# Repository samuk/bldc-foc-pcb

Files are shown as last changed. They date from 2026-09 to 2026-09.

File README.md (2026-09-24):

# FOC BLDC Motor Controller

> High-performance Field-Oriented Control driver built around the **STM32G474** MCU and **DRV8308** gate driver.

**[🌐 Live Project Page](https://bejaouihamza.github.io/bldc-foc-pcb/)**

[Kicanvas](https://kicanvas.org/?repo=https%3A%2F%2Fgithub.com%2Fsamuk%2Fbldc-foc-pcb%2Ftree%2Fmain%2Fkicad)

---

## Overview

This open-source hardware project is a compact, single-board FOC (Field-Oriented Control) motor driver designed for precision robotics, drones, CNC machines, and automation systems. It delivers smooth sinusoidal torque control with minimal audible noise thanks to Space Vector PWM (SVPWM) modulation.

| Spec | Value |
|---|---|
| Input Voltage | 8.5V – 32V DC |
| Max Continuous Current | 50A |
| Peak Current | 100A (transient) |
| MCU | STM32G474CBTx (170 MHz, Cortex-M4) |
| Gate Driver | DRV8308 (SPI-configurable) |
| MOSFETs | 6× BSC098N10NS5 (100V, 9.8mΩ) |
| PWM Frequency | 20 kHz (center-aligned) |
| Commutation | Trapezoidal or 180° sinusoidal FOC |
| Sensors | 3× Hall differential inputs |
| Interface | USB-C + ARM SWD debug |

---

## Hardware

### PCB Layout (Top Layer)

PCB Top Layer Layout

The top layer shows the complete copper layout with phase outputs **U, V, W** at the top, power input (**XT60**) on the left, and the control section (STM32G474 + DRV8308) in the center. Note the star-grounding strategy and wide power traces for high-current paths.

### 3D Render

PCB 3D Render

Compact form factor (~85mm × 55mm) with 4× M3 mounting holes. The large electrolytic capacitors handle bulk energy storage while the XT60 connector delivers main battery power.

### Schematic

Full Schematic

The design is organized into clear functional blocks:
- **Power Input & Protection** — XT60 connector, fuse, reverse-polarity diode, LTC4359 ideal diode
- **5V Buck** — LM5164DDA switching regulator
- **3.3V LDO** — TLV75533 for clean logic supply
- **MCU** — STM32G474 with 24MHz crystal, USB-C, SWD, BOOT/RESET switches
- **FOC Unit** — DRV8308 gate driver with SPI configuration
- **Power Stage** — 6× BSC098N10NS5 MOSFETs in 3-phase bridge configuration
- **Hall Sensors** — 3× DRV5013 with 4.7kΩ pull-ups and VREG supply

---

## Architecture

### FOC Control Loop

```
                Speed Ref (ω*) → Speed PI → Iq*
                                ↓
                    ┌─────────────────┐
Id*=0 → Current PI  │  Inverse Park   │ → Vα,Vβ → SVPWM → DRV8308 → 3-Phase Bridge → Motor
  Iq → Current PI   │  (d-q → α-β)    │         ↑
                    └─────────────────┘         │
                            ↑                   │
  Hall → Estimator → θ,ω    │                   │
           ↑                │                   │
    Current Sense → Clarke → Park → Id,Iq (feedback)
```

The STM32G474 runs the full FOC algorithm:
1. **Speed PI** — compares reference vs. actual speed, outputs torque command
2. **Current PI (×2)** — regulates Id=0 and Iq=Iq* in the rotating d-q frame
3. **Inverse Park** — converts Vd,Vq → Vα,Vβ (rotating → stationary)
4. **SVPWM** — Space Vector modulation for 15% better DC bus utilization vs. sine PWM
5. **Feedback** — Hall sensors provide rotor position; 5mΩ shunt (R1) senses phase current

### Critical Pin Assignment

| Pin | Function | Connected To |
|-----|---|---|
| **PA8** | TIM1_CH1 / CLKIN | DRV8308 CLKIN *(most important!)* |
| PA4-PA7 | SPI1 | DRV8308 SCS/SCLK/SDATAO/SDATAI |
| PB0 | DIRECTION | DRV8308 DIR |
| PB1 | SHDN | DRV8308 SHDN |
| PB7 | ENABLE | DRV8308 ENABLE |
| PB4 | FAULTn | DRV8308 FAULTn (input) |

> ⚠️ **TIM1_CH1 on PA8 is critical** — it synchronizes DRV8308 internal commutation timing. Moving it to a general-purpose timer breaks center-aligned PWM alignment.

---

## Firmware

### STM32 HAL Example

```c
/* Initialize DRV8308 for 180° sinusoidal FOC */
void DRV8308_Init(void) {
    // SYSOPT1: Enable sine mode
    DRV8308_WriteReg(DRV8308_SYSOPT1, 0x8000);  // SINMODE=1

    // SYSOPT2: 50mA gate drive for BSC098N10NS5
    DRV8308_WriteReg(DRV8308_SYSOPT2, 0x0300);  // IDRIVE=011

    // SYSOPT3: 1µs dead time
    DRV8308_WriteReg(DRV8308_SYSOPT3, 0x0040);

    // SYSOPT9: 50A overcurrent (0.25V / 5mΩ)
    DRV8308_WriteReg(DRV8308_SYSOPT9, 0x0000);
}

/* TIM1 center-aligned PWM for CLKIN */
void TIM1_PWM_Init(void) {
    htim1.Instance = TIM1;
    htim1.Init.Prescaler = 0;
    htim1.Init.CounterMode = TIM_COUNTERMODE_CENTERALIGNED1;
    htim1.Init.Period = 4250;  // 170MHz / (2×4250) = 20kHz
    // ...
    HAL_TIM_PWM_Start(&htim1, TIM_CHANNEL_1);
}
```

### Arduino / SimpleFOC

Also compatible with the [SimpleFOC](https://simplefoc.com/) library for rapid prototyping:

```cpp
BLDCMotor motor = BLDCMotor(11);  // 11 pole pairs
BLDCDriver3PWM driver = BLDCDriver3PWM(9, 10, 11, 8);
HallSensor sensor = HallSensor(2, 3, 4, 11);

motor.foc_modulation = FOCModulationType::SpaceVectorPWM;
motor.controller = MotionControlType::velocity;
motor.init();
motor.initFOC();
```

See the **[live project page](https://bejaouihamza.github.io/bldc-foc-pcb/)** for the complete code examples, wiring guide, and interactive SVPWM block diagram.

---

## Wiring

| Connection | Pin/Port | Notes |
|---|---|---|
| Battery | XT60 | 8.5-32V DC |
| Motor U/V/W | Top screw terminals | Thick wire, high current |
| Hall VCC | VREG pin | 5V from DRV8308 |
| Hall GND | GND pin | Common ground |
| Hall signals | UHP/UHN, VHP/VHN, WHP/WHN | Differential pairs |
| Programming | SWD header | ST-Link V2/V3 |
| Serial/USB | USB-C | DFU bootloader + CDC |

---

## Bill of Materials (Key Components)

| Ref | Part | Description |
|-----|---|---|
| U1 | STM32G474CBTx | 170 MHz Cortex-M4 MCU |
| U2 | DRV8308 | 3-phase gate driver with SPI |
| Q1-Q6 | BSC098N10NS5 | 100V, 9.8mΩ N-channel MOSFET |
| U6 | LM5164DDA | 5V buck converter |
| U7 | TLV75533PDBV | 3.3V LDO |
| U8 | LTC4359 | Ideal diode controller |
| U3-U5 | DRV5013 | Hall sensors |
| Y1 | 24 MHz | Crystal oscillator |
| J1 | XT60PW-M | Battery connector |
| J5 | USB-C | USB 2.0 receptacle |

---

## Protection Features

- ✅ Reverse polarity (LTC4359 + diode)
- ✅ Overcurrent (cycle-by-cycle, 50A limit)
- ✅ Undervoltage lockout (UVLO)
- ✅ Overtemperature shutdown
- ✅ Rotor lock detection
- ✅ Fuse on battery input

---

## Getting Started

1. **Power up** — Connect 12-24V battery to XT60. Verify 5V and 3.3V LEDs.
2. **Connect motor** — Wire BLDC phases and Hall sensors.
3. **Flash firmware** — Use ST-Link on SWD header or DFU over USB-C.
4. **Configure DRV8308** — Run SPI init sequence (see code above).
5. **Spin** — Enable driver, set direction, send CLKIN frequency. Start at 100 Hz, ramp up slowly.

---

## Project Structure

```
bldc-foc-pcb/
├── README.md                          # Project overview and documentation
├── index.html                         # GitHub Pages project page
├── pcb-layout-top.png                 # Top-layer PCB layout
├── pcb-render.png                     # 3D render of the assembled PCB
├── schematic-full.png                 # Complete circuit schematic
├── bldc&foc motor controller.zip      # Complete KiCad project source
├── bldcfoc_motor_controller.zip       # Manufacturing files (Gerbers, drill, etc.)
├── bom.csv                            # Bill of Materials for assembly
├── designators.csv                    # Reference designator list
├── netlist.ipc                        # IPC-D-356 netlist for verification
└── positions.csv                      # Pick-and-place coordinates for SMT assembly
```

---

## License

Open source hardware. Feel free to use, modify, and distribute. Attribution appreciated.

---

**Designed by [bejaoui hamza](https://github.com/bejaouihamza)** · KiCad EDA 10.0.1

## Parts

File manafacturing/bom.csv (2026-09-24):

Designator | Footprint | Quantity | Value | LCSC Part #
C1, C19, C20 | CP_Elec_8x10.5 | 3 | 470u
C10, C25, C27 | 0603 | 3 | 0.01U
C11 | 0603 | 1 | 2.2n
C12 | 0805 | 1 | 2.2u
C13 | CP_EIA-3528-21_Kemet-B | 1 | 47u
C14, C15, C24, C26, C3, C5 | 0805 | 6 | 1u
C16, C17, C18 | CP_Elec_6.3x7.7 | 3 | 220u
C2, C21, C22, C23, C4, C6, C7, C8, C9 | 0603 | 9 | 0.1u
C28, C29 | 0603 | 2 | 15P
D1 | D_SMC | 1 | 1.5SMCxxCA
D12, D13 | 0805 | 2 | LED_Small | C2297
D2, D3 | D_SMC | 2 | MBRS340
F1 | Fuse_Blade_Mini_directSolder | 1 | Fuse
FB1 | 1210 | 1 | FerriteBead
J1 | AMASS_XT60PW-M | 1 | XT60PW-M
J5 | USB_C_Receptacle_HRO_TYPE-C-31-M-12 | 1 | USB_C_Receptacle_USB2.0_14P | C165948
L1 | L_APV_ANR4012 | 1 | 68u
Q1, Q2, Q3, Q4, Q5, Q6 | TDSON-8-1 | 6 | BSC098N10NS5
Q7 | TDSON-8-1 | 1 | BSC026N08NS5
R1 | 2512 | 1 | 5m
R10, R11, R2, R4, R5, R6, R7, R8, R9 | 0603 | 9 | 4.7K
R12 | 0603 | 1 | 475k
R13 | 0603 | 1 | 150k
R14, R32 | 0603 | 2 | 100k
R15, R30 | 0603 | 2 | 5.1K | C27834
R16, R18, R23, R28, R29 | 0603 | 5 | 22
R17, R19, R20, R21, R22, R24, R25, R26, R27, R31, R37 | 0603 | 11 | 10k
R33 | 0603 | 1 | 1k
R34 | 0603 | 1 | 100
R59, R60 | 0402 | 2 | 1.5k
SW1, SW2 | SW_TH_Tactile_Omron_B3F-100x | 2 | SW_Push_Dual_x2
TP1, TP2, TP3, TP4 | TestPoint_Pad_D1.5mm | 4 | TestPoint
U1 | LQFP-48_7x7mm_P0.5mm | 1 | STM32G474CBTx
U11 | SOT-23-6 | 1 | USBLC6-2SC6
U2 | Texas_RHA0040E_VQFN-40-1EP_6x6mm_P0.5mm_EP3.52x2.62mm | 1 | DRV8308
U6 | HSOP-8-1EP_3.9x4.9mm_P1.27mm_EP2.41x3.1mm_ThermalVias | 1 | LM5164DDA
U7 | SOT-23-5 | 1 | TLV75533PDBV
U8 | DFN-6-1EP_3x2mm_P0.5mm_EP1.65x1.35mm | 1 | LTC4359-DCB
Y1 | Crystal_SMD_3225-4Pin_3.2x2.5mm | 1 | Crystal_GND23

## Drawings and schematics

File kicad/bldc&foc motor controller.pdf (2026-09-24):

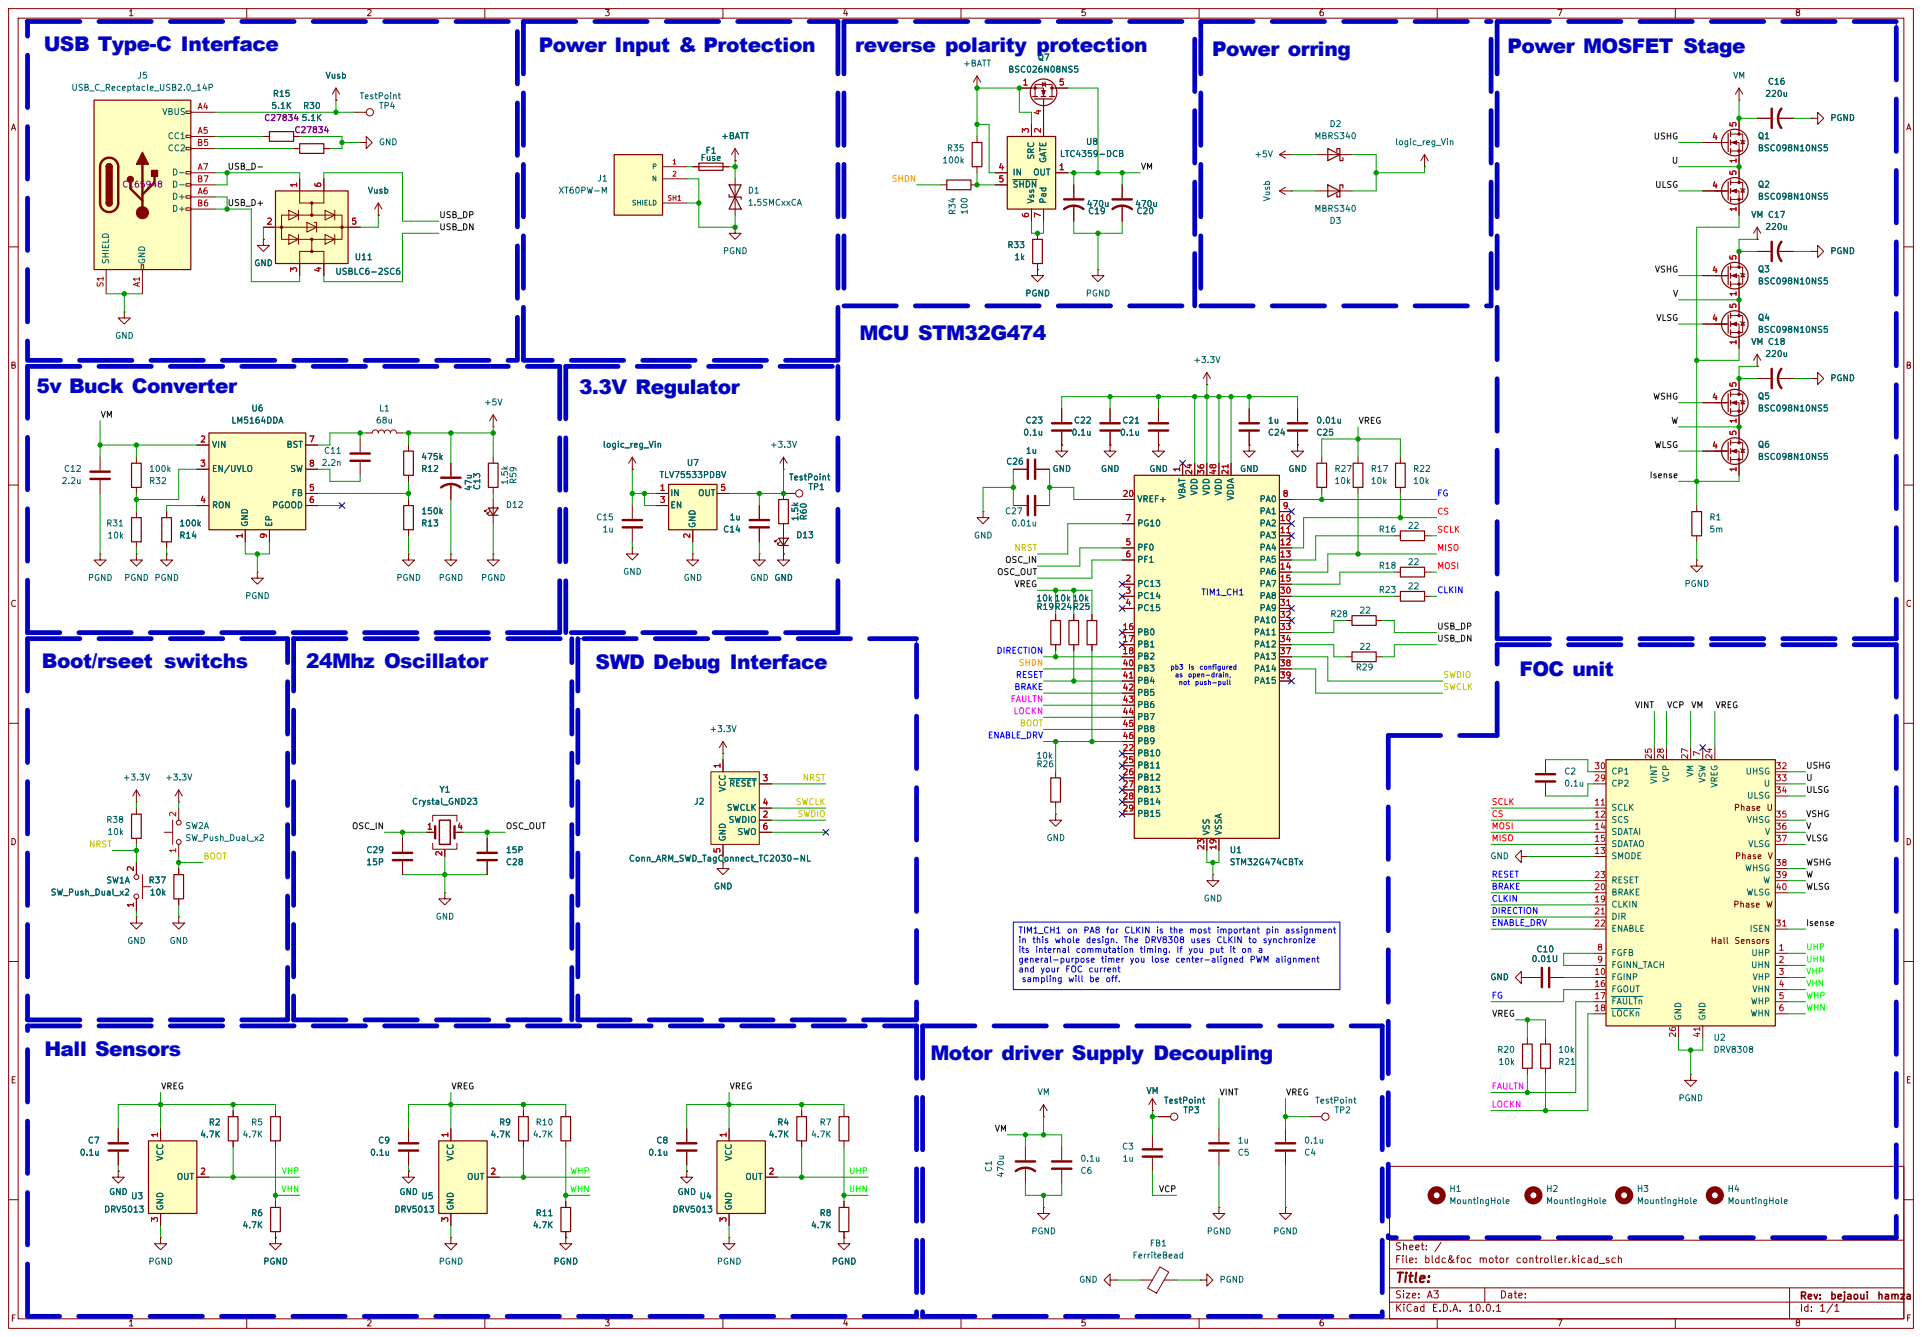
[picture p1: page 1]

pb3 is configured as open-drain, not push-pull

TIM1_CH1 on PA8 for CLKIN is the most important pin assignment
in this whole design. The DRV8308 uses CLKIN to synchronize
its internal commutation timing. If you put it on a
general-purpose timer you lose center-aligned PWM alignment and your FOC current sampling will be off.

Motor driver Supply Decoupling

File: bldc&foc motor controller.kicad_sch
Title:

F Date:

KiCad E.D.A. 10.0.1 | Id: 1/1

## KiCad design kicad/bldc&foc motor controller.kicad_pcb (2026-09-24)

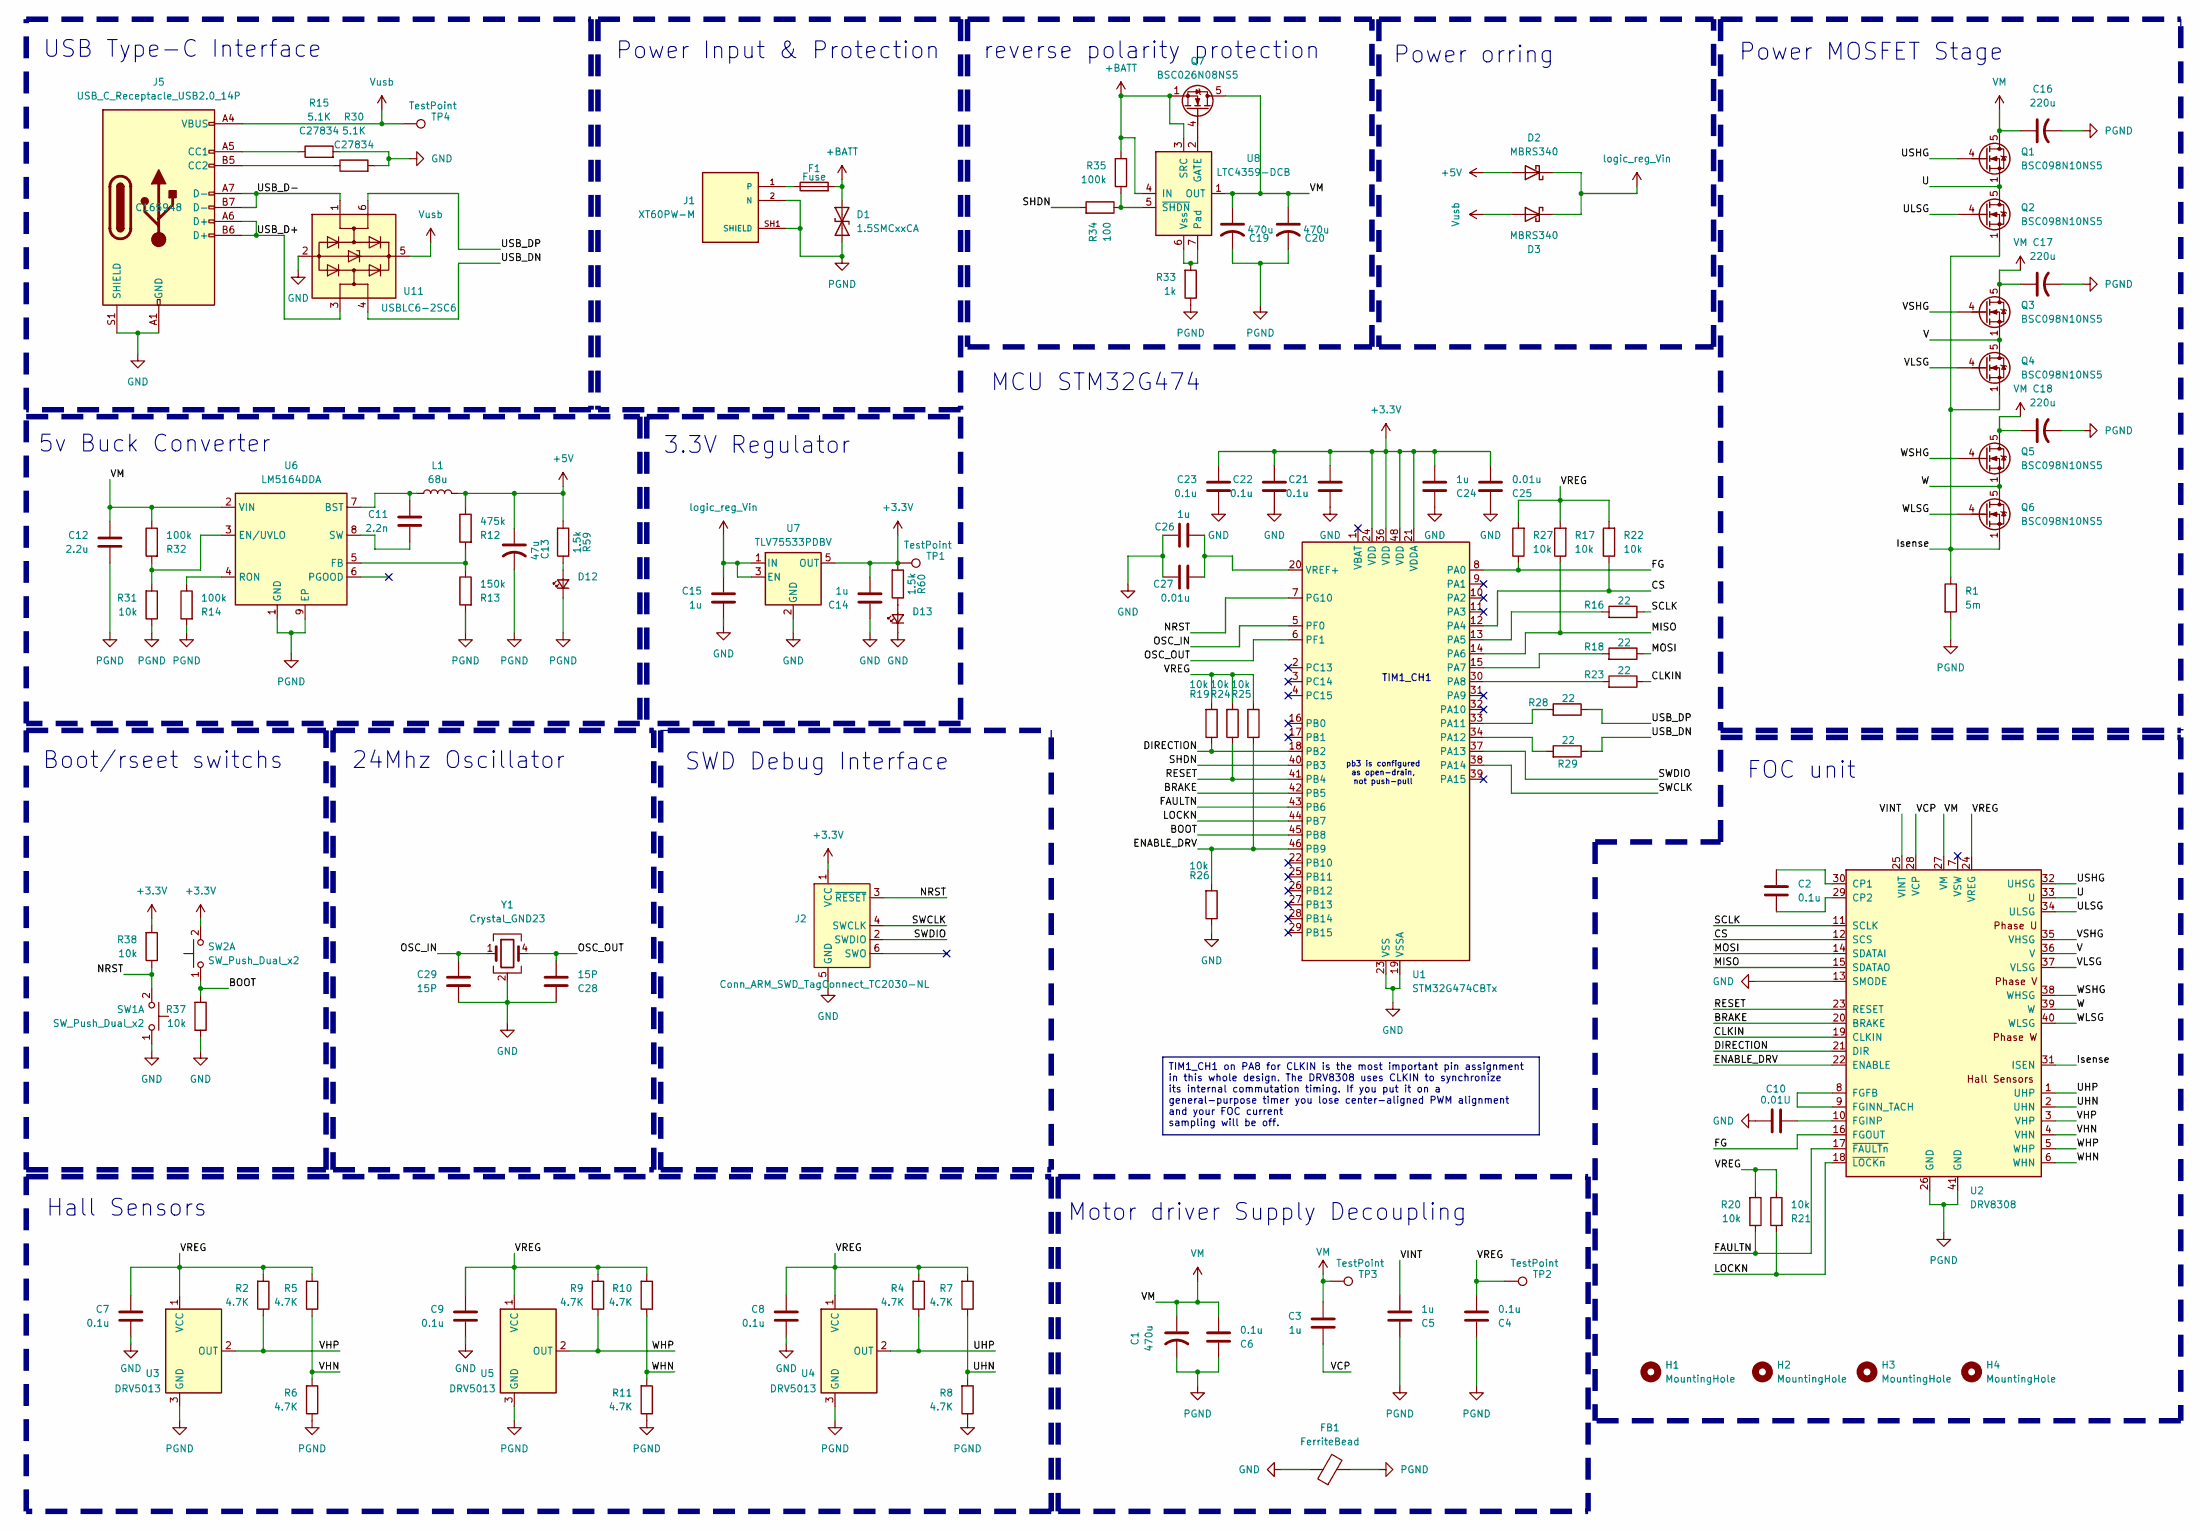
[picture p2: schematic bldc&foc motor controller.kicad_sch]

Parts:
C1, C19, C20: 470u; CP_Elec_8x10.5
C2, C4, C6, C7, C8, C9, C21, C22, C23: 0.1u; C_0603_1608Metric
C3, C5, C14, C15, C24, C26: 1u; C_0805_2012Metric
C10: 0.01U; C_0603_1608Metric
C11: 2.2n; C_0603_1608Metric
C12: 2.2u; C_0805_2012Metric
C13: 47u; CP_EIA-3528-21_Kemet-B
C16, C17, C18: 220u; CP_Elec_6.3x7.7
C25, C27: 0.01u; C_0603_1608Metric
C28, C29: 15P; C_0603_1608Metric
D1: 1.5SMCxxCA; D_SMC
D2, D3: MBRS340; D_SMC
D12, D13: LED_Small; LED_0805_2012Metric; LCSC Part # C2297
F1: Fuse; Fuse_Blade_Mini_directSolder
FB1: FerriteBead; L_1210_3225Metric
H1, H2, H3, H4: MountingHole; MountingHole_3.5mm_Pad_TopBottom
J1: XT60PW-M; AMASS_XT60PW-M; PARTREV 1.2
J2: Conn_ARM_SWD_TagConnect_TC2030-NL; Tag-Connect_TC2030-IDC-NL_2x03_P1.27mm_Vertical
J5: USB_C_Receptacle_USB2.0_14P; USB_C_Receptacle_HRO_TYPE-C-31-M-12; LCSC Part # C165948
L1: 68u; L_APV_ANR4012
Q1, Q2, Q3, Q4, Q5, Q6: BSC098N10NS5; TDSON-8-1
Q7: BSC026N08NS5; TDSON-8-1
R1: 5m; R_2512_6332Metric
R2, R4, R5, R6, R7, R8, R9, R10, R11: 4.7K; R_0603_1608Metric
R12: 475k; R_0603_1608Metric
R13: 150k; R_0603_1608Metric
R14, R32: 100k; R_0603_1608Metric
R15, R30: 5.1K; R_0603_1608Metric; LCSC Part # C27834
R16, R18, R23, R28, R29: 22; R_0603_1608Metric
R17, R19, R20, R21, R22, R24, R25, R26, R27, R31, R37: 10k; R_0603_1608Metric
R33: 1k; R_0603_1608Metric
R34: 100; R_0603_1608Metric
R35: 100k
R38: 10k
R59, R60: 1.5k; R_0402_1005Metric
SW1, SW2: SW_Push_Dual_x2; SW_TH_Tactile_Omron_B3F-100x
TP1, TP2, TP3, TP4: TestPoint; TestPoint_Pad_D1.5mm
U1: STM32G474CBTx; LQFP-48_7x7mm_P0.5mm
U2: DRV8308; Texas_RHA0040E_VQFN-40-1EP_6x6mm_P0.5mm_EP3.52x2.62mm
U3, U4, U5: DRV5013; SOT-23
U6: LM5164DDA; HSOP-8-1EP_3.9x4.9mm_P1.27mm_EP2.41x3.1mm_ThermalVias
U7: TLV75533PDBV; SOT-23-5
U8: LTC4359-DCB; DFN-6-1EP_3x2mm_P0.5mm_EP1.65x1.35mm
U11: USBLC6-2SC6; SOT-23-6; Manufacturer_Part_Number USBLC6-2SC6; Mouser Part Number 511-USBLC6-2SC6
Y1: Crystal_GND23; Crystal_SMD_3225-4Pin_3.2x2.5mm

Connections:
+3.3V: C14.2, C21.1, C22.1, C23.1, C24.2, C25.2, J2.1 (VCC), R38.2, R60.2, SW2.2 (D), TP1.1 (1_1), U1.21 (VDDA), U1.24 (VDD), U1.36 (VDD), U1.48 (VDD), U7.5 (OUT)
+5V: C13.1, D2.2 (A), L1.2, R12.1, R59.2
+BATT: D1.1 (A1), F1.2, Q7.1 (S), Q7.2 (S), Q7.3 (S), R35.2, U8.3 (SRC), U8.4 (IN)
/BOOT: R37.2, SW2.1 (C), U1.45 (PB8)
/BRAKE: U1.42 (PB5), U2.20 (BRAKE)
/CLKIN: R23.1, U2.19 (CLKIN)
/CS: R22.1, U1.12 (PA4), U2.12 (SCS)
/DIRECTION: R19.1, U1.18 (PB2), U2.21 (DIR)
/ENABLE_DRV: R25.1, R26.2, U1.46 (PB9), U2.22 (ENABLE)
/FAULTN: R20.1, U1.43 (PB6), U2.17 (~FAULTn)
/FG: R27.1, U1.8 (PA0), U2.16 (FGOUT)
/Isense: Q2.1 (S), Q2.2 (S), Q2.3 (S), Q4.1 (S), Q4.2 (S), Q4.3 (S), Q6.1 (S), Q6.2 (S), Q6.3 (S), R1.1, U2.31 (ISEN)
/LOCKN: R21.2, U1.44 (PB7), U2.18 (~LOCKn)
/MISO: R17.1, U1.14 (PA6), U2.15 (SDATAO)
/MOSI: R18.1, U2.14 (SDATAI)
/NRST: J2.3 (~RESET), R38.1, SW1.2 (D), U1.7 (PG10)
/OSC_IN: C29.1, U1.5 (PF0), Y1.1
/OSC_OUT: C28.2, U1.6 (PF1), Y1.4
/RESET: R24.1, U1.41 (PB4), U2.23 (RESET)
/SCLK: R16.1, U2.11 (SCLK)
/SHDN: R34.2, U1.40 (PB3)
/SWCLK: J2.4 (SWCLK), U1.38 (PA14)
/SWDIO: J2.2 (SWDIO), U1.37 (PA13)
/U: Q1.1 (S), Q1.2 (S), Q1.3 (S), Q2.5 (D), U2.33 (U)
/UHN: R7.1, R8.2, U2.2 (UHN)
/UHP: R4.1, U2.1 (UHP), U4.2 (OUT)
/ULSG: Q2.4 (G), U2.34 (ULSG)
/USB_D+: J5.A6 (D+), J5.B6 (D+), U11.3 (I/O2)
/USB_D-: J5.A7 (D-), J5.B7 (D-), U11.1 (I/O1)
/USB_DN: R29.1, U11.4 (I/O2)
/USB_DP: R28.1, U11.6 (I/O1)
/USHG: Q1.4 (G), U2.32 (UHSG)
/V: Q3.1 (S), Q3.2 (S), Q3.3 (S), Q4.5 (D), U2.36 (V)
/VCP: C3.2, U2.28 (VCP)
/VHN: R5.1, R6.2, U2.4 (VHN)
/VHP: R2.1, U2.3 (VHP), U3.2 (OUT)
/VINT: C5.2, U2.25 (VINT)
/VLSG: Q4.4 (G), U2.37 (VLSG)
/VREG: C4.2, C7.1, C8.1, C9.1, R2.2, R4.2, R5.2, R7.2, R9.2, R10.2, R17.2, R19.2, R20.2, R21.1, R22.2, R24.2, R25.2, R27.2, TP2.1 (1_1), U2.24 (VREG), U3.1 (VCC), U4.1 (VCC), U5.1 (VCC)
/VSHG: Q3.4 (G), U2.35 (VHSG)
/W: Q5.1 (S), Q5.2 (S), Q5.3 (S), Q6.5 (D), U2.39 (W)
/WHN: R10.1, R11.2, U2.6 (WHN)
/WHP: R9.1, U2.5 (WHP), U5.2 (OUT)
/WLSG: Q6.4 (G), U2.40 (WLSG)
/WSHG: Q5.4 (G), U2.38 (WHSG)
GND: C7.2, C8.2, C9.2, C10.2, C14.1, C15.2, C21.2, C22.2, C23.2, C24.1, C25.1, C26.1, C27.1, C28.1, C29.2, D13.1 (K), FB1.1, J2.5 (GND), J5.A1 (GND), J5.A12 (GND), J5.B1 (GND), J5.B12 (GND), J5.S1 (SHIELD), R15.2, R26.1, R30.2, R37.1, SW1.1 (C), U1.19 (VSSA), U1.23 (VSS), U1.35 (VSS), U1.47 (VSS), U2.13 (SMODE), U7.2 (GND), U11.2 (GND), Y1.2 (G), Y1.3 (G)
unnamed: D12.2 (A), R59.1
unnamed: D13.2 (A), R60.1
unnamed: F1.1, J1.1
unnamed: J5.A5 (CC1), R15.1
unnamed: J5.B5 (CC2), R30.1
unnamed: Q7.4 (G), U8.2 (GATE)
unnamed: R16.2, U1.13 (PA5)
unnamed: R18.2, U1.15 (PA7)
unnamed: R23.2, U1.30 (PA8)
unnamed: R28.2, U1.33 (PA11)
unnamed: R29.2, U1.34 (PA12)
unnamed: C26.2, C27.2, U1.20 (VREF+)
unnamed: C2.1, U2.30 (CP1)
unnamed: C2.2, U2.29 (CP2)
unnamed: U2.8 (FGFB), U2.9 (FGINN_TACH)
unnamed: C10.1, U2.10 (FGINP)
unnamed: C11.1, L1.1, U6.7 (BST)
unnamed: R31.2, R32.2, U6.3 (EN/UVLO)
unnamed: R12.2, R13.1, U6.5 (FB)
unnamed: R14.1, U6.4 (RON)
unnamed: C11.2, U6.8 (SW)
unnamed: R33.2, U8.6 (Vss), U8.7 (Pad)
unnamed: R34.1, R35.1, U8.5 (~SHDN)
PGND: C1.2, C4.1, C5.1, C6.1, C12.2, C13.2, C16.2, C17.2, C18.2, C19.2, C20.2, D1.2 (A2), D12.1 (K), FB1.2, J1.2 (N), J1.SH1 (SHIELD), J1.SH2 (SHIELD), R1.2, R6.1, R8.1, R11.1, R13.2, R14.2, R31.1, R33.1, U2.26 (GND), U2.41 (GND), U3.3 (GND), U4.3 (GND), U5.3 (GND), U6.1 (GND), U6.9 (EP)
VM: C1.1, C3.1, C6.2, C12.1, C16.1, C17.1, C18.1, C19.1, C20.1, Q1.5 (D), Q3.5 (D), Q5.5 (D), Q7.5 (D), R32.1, TP3.1 (1_1), U2.27 (VM), U6.2 (VIN), U8.1 (OUT)
Vusb: D3.2 (A), J5.A4 (VBUS), J5.A9 (VBUS), J5.B4 (VBUS), J5.B9 (VBUS), TP4.1 (1_1), U11.5 (VBUS)
logic_reg_Vin: C15.1, D2.1 (K), D3.1 (K), U7.1 (IN), U7.3 (EN)

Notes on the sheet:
pb3 is configured as open-drain, not push-pull
3.3V Regulator
USB Type-C Interface
Boot/rseet switchs
Power MOSFET Stage
24Mhz Oscillator
MCU STM32G474
Power Input & Protection
reverse polarity protection
TIM1_CH1
SWD Debug Interface
Motor driver Supply Decoupling
Hall Sensors
5v Buck Converter
FOC unit
Power orring
TIM1_CH1 on PA8 for CLKIN is the most important pin assignment in this whole design. The DRV8308 uses CLKIN to synchronize its internal commutation timing. If you put it on a general-purpose timer you lose center-aligned PWM alignment and your FOC current sampling will be off.

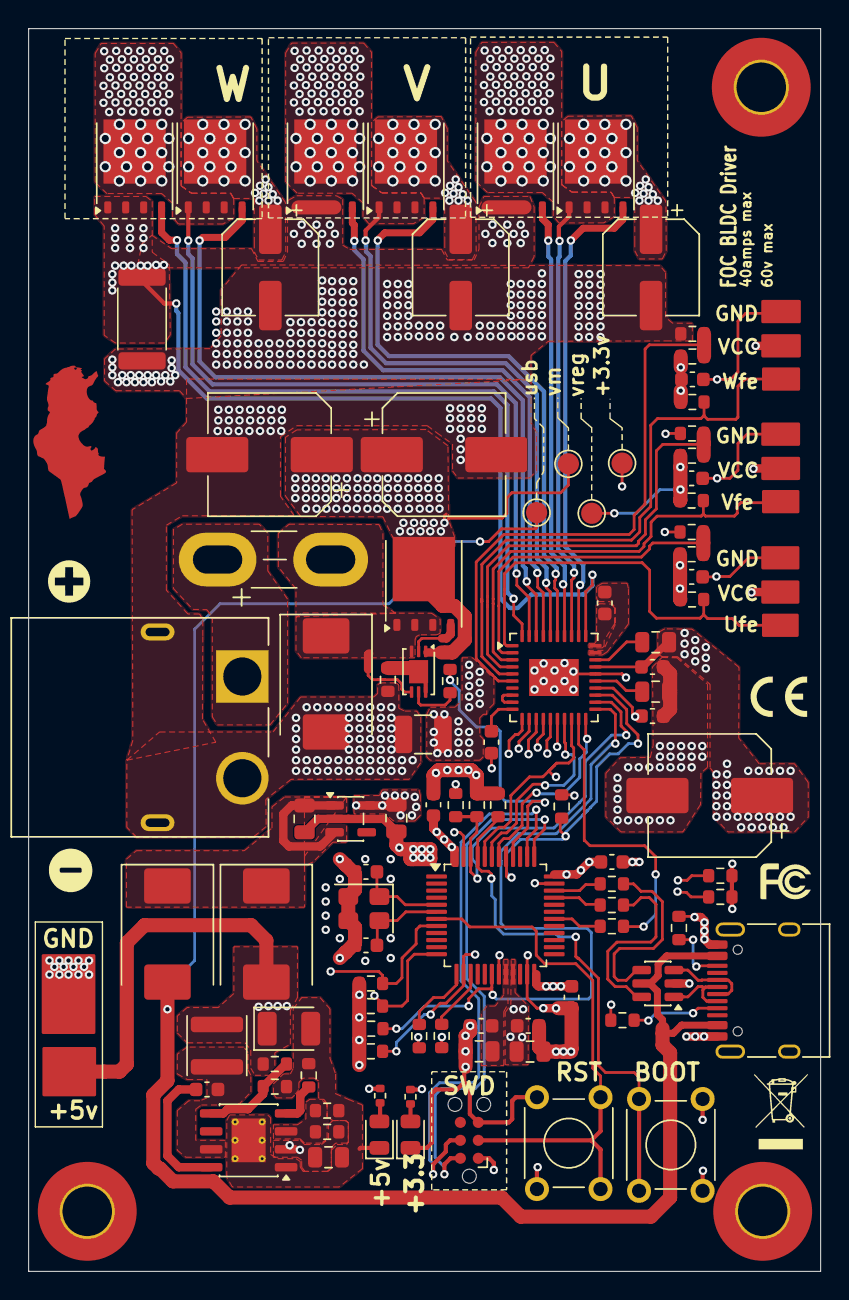
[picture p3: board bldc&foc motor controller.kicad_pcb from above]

Board: 6 copper layers, 56.1 x 88.0 mm, 99 parts (0 on the bottom side), 73 nets.

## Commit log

2026-09-24 Add unzipped BLDC motor controller
    [bldc&foc motor controller-B_Cu.gbl, bldc&foc motor controller-B_Mask.gbs, bldc&foc motor controller-B_Paste.gbp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]
2026-09-24 re-order into folders
    [bldc&foc motor controller-B_Cu.gbl, bldc&foc motor controller-B_Mask.gbs, bldc&foc motor controller-B_Paste.gbp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]
2026-09-24 Add Kicanvas link to README
    Added link to Kicanvas for PCB design access.
